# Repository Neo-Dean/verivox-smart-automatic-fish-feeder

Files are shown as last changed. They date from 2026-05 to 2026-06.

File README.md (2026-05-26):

# VERIVOX: Smart Aquarium Management System 🌊🤖

VERIVOX is an IoT-enabled smart fish feeder and water quality management system designed for residential aquariums. It ensures fish survival and optimal water chemistry through real-time monitoring, automated feeding schedules, and hierarchical safety lockouts.

## 🚀 Core Features
* **Priority Safety Lockouts:** Automatically halts feeding and triggers visual/mobile alarms if water pH crashes to toxic levels.
* **Smart Maintenance Alerts:** Continues offline feeding but alerts users when TDS or Turbidity thresholds indicate a dirty tank.
* **Dual-Redundancy Scheduling:** Syncs with the Arduino IoT Cloud via mobile UI sliders, backed by a local DS3231 RTC module to guarantee feeding even during total Wi-Fi blackouts.
* **Chemical Dosing Control:** Integrates an MD-102 driven peristaltic pump with 2FA mobile confirmation to safely correct pH imbalances.

## 💻 Tech Stack & Electronics
* **Microcontroller:** Arduino Nano 33 IoT
* **Cloud Infrastructure:** Arduino IoT Cloud (Dashboards & Webhooks)
* **Sensors:** pH, TDS, Turbidity, DS18B20 (Temperature for polynomial TDS compensation), HC-SR04 (Food level monitoring).
* **Actuators:** MG996R Servo (Feeder), Peristaltic Pump via MD-102 Driver.

## ⚙️ Open-Source Hardware & 3D Enclosure
The physical architecture of VERIVOX was custom-engineered using Fusion 360. All CAD files are provided in the `/3d model` directory to support the Open-Source Hardware (OSHW) community.

* **Interactive Assembly:** Click on the `VERIVOX_Full_Assembly.stl` file within GitHub to view and rotate the fully assembled hardware in 3D.
* **Manufacturing Ready:** Individual components (Main Body, Lid, Motor Mount, Worm-Screw, etc.) are provided in modern `.3mf` format, preserving crucial slicing data for 3D printing.

## 🧠 System Architecture Highlight
This repository contains the production firmware for the VERIVOX mainboard. The code is optimized to minimize server payload using delta thresholds (`thingProperties.h`) and features strict interrupt management (`IrReceiver.stop()`) to prevent timer conflicts between the IR hardware and PWM servo signals.

---
*Developed as a Final Year Software Engineering Project by Syajaratul Diana at Universiti Malaysia Sarawak (UNIMAS).*

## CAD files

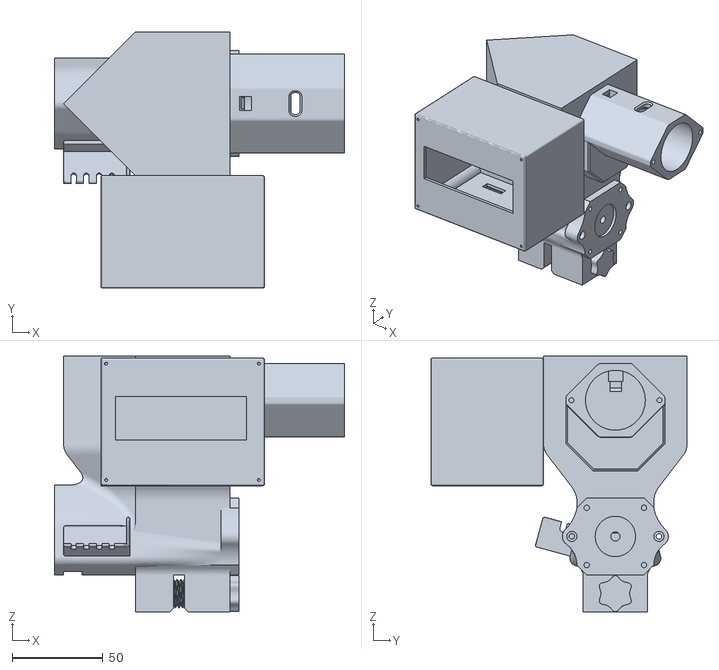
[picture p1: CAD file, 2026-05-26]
3d model/Assembled-automatic-fish-feeder.stl
159.5 x 141.0 x 140.6

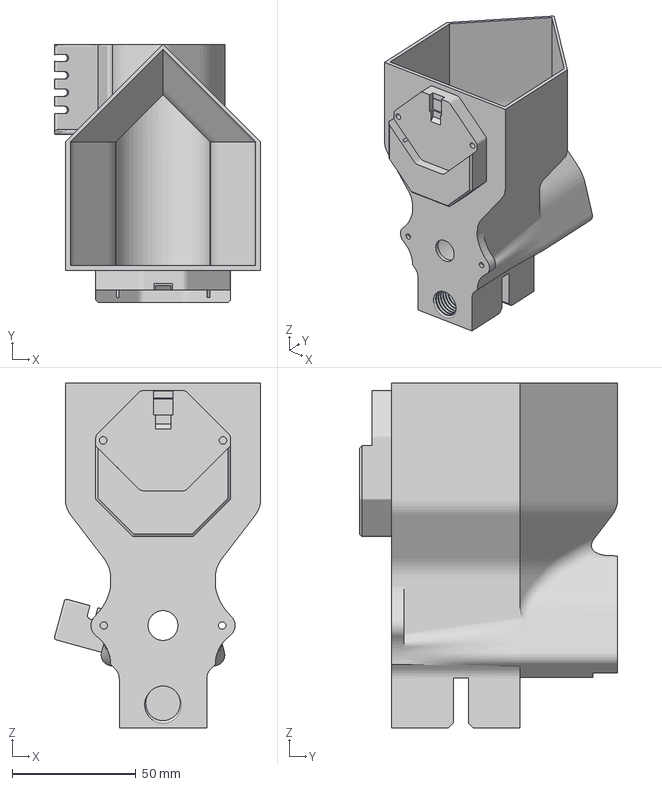
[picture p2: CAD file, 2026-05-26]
3d model/mainbody.3mf
83.5 x 104.5 x 139.6 mm

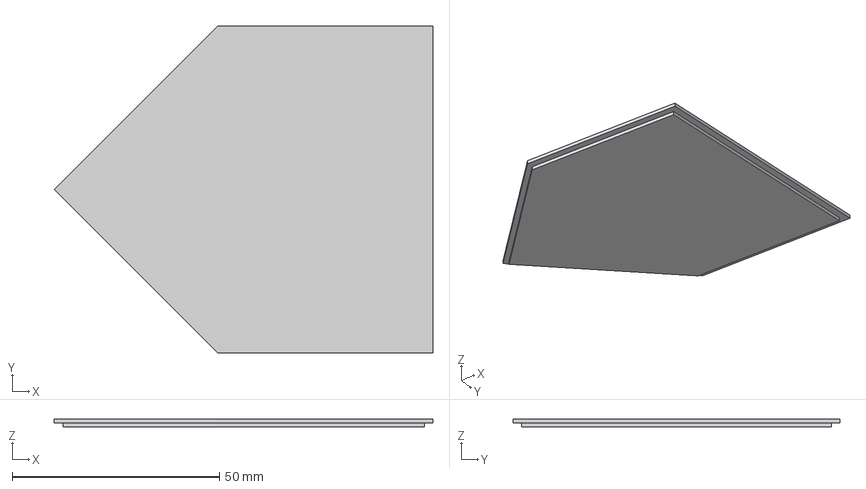
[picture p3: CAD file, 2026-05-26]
3d model/cover.3mf
91.5 x 79.0 x 2.00 mm

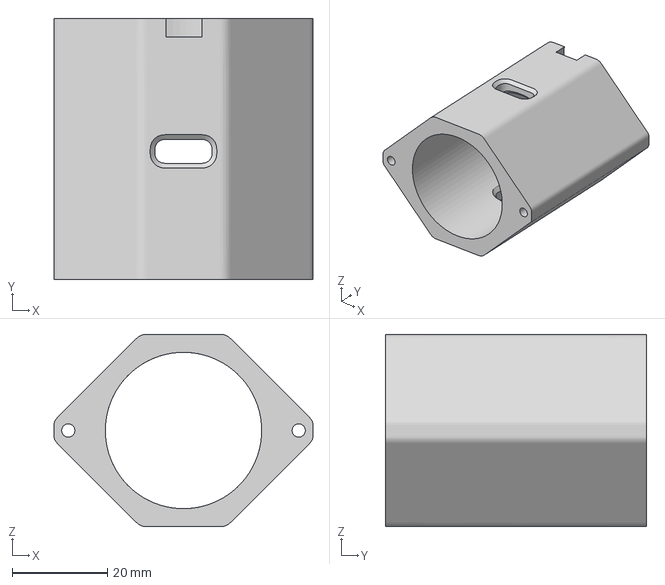
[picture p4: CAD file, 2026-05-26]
3d model/pump body.3mf
54.5 x 55.0 x 40.5 mm

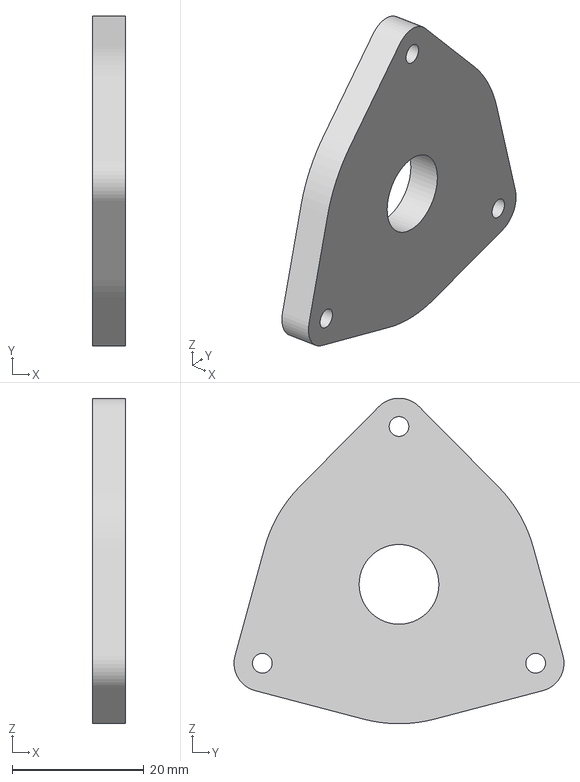
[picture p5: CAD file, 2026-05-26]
3d model/lock.3mf
5.00 x 50.1 x 49.4 mm

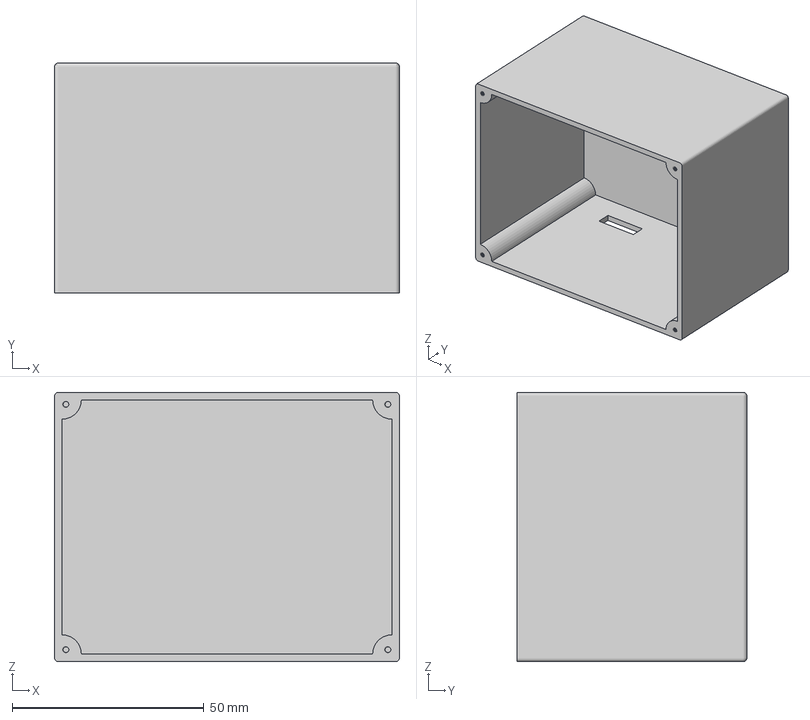
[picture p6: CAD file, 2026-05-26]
3d model/box.3mf
90.0 x 60.0 x 70.3 mm

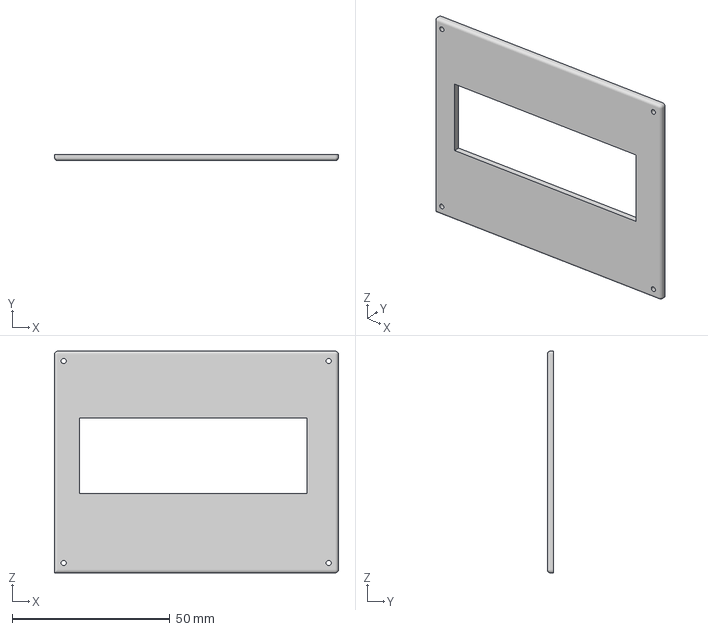
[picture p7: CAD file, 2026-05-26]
3d model/lid.3mf
90.0 x 2.00 x 70.3 mm

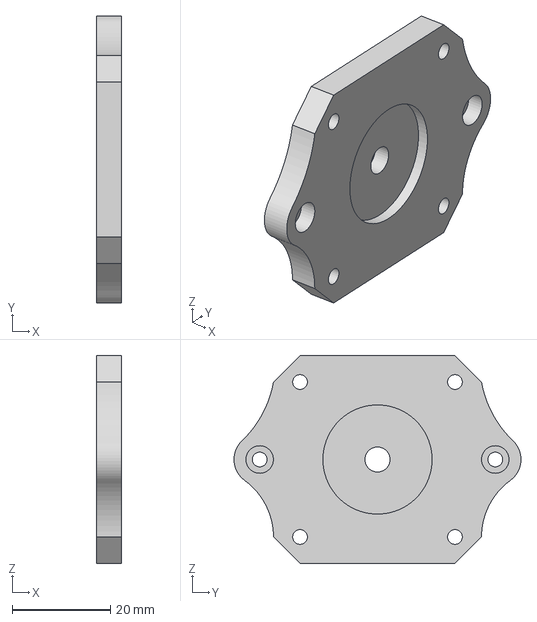
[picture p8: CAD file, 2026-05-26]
3d model/motor-mount.3mf
5.00 x 58.3 x 42.3 mm

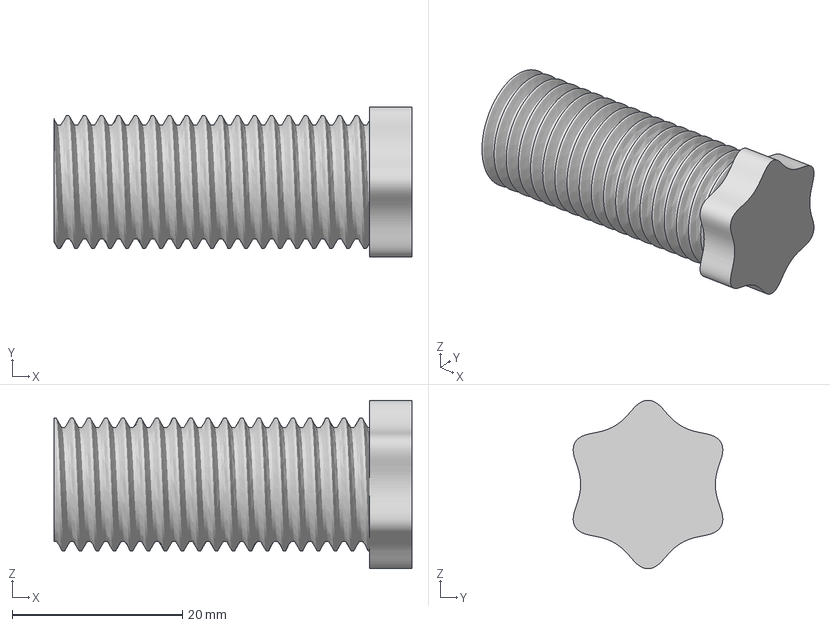
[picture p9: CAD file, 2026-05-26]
3d model/tightening-screw.3mf
42.1 x 17.6 x 19.8 mm

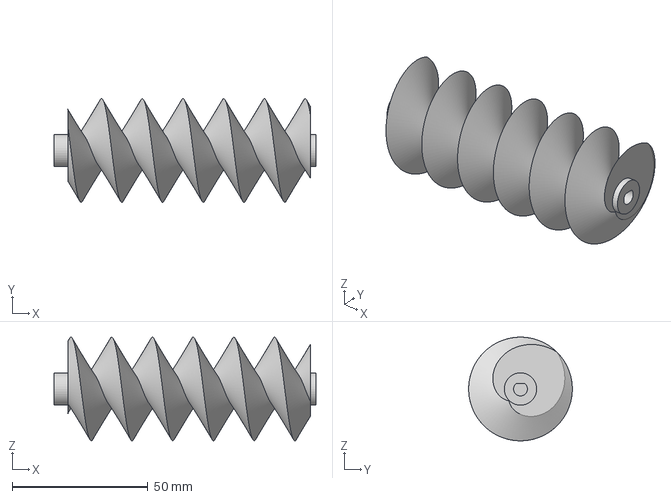
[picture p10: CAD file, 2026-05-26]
3d model/worm-screw.3mf
96.5 x 38.2 x 38.2 mm

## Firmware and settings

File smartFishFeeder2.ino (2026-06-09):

#include "thingProperties.h"
// 1. Core Communication (Must go first!)
#include <Wire.h>

// 2. LCD Screen Libraries
#include <hd44780.h>
#include <hd44780ioClass/hd44780_I2Cexp.h>

// 3. Sensors and Actuators
#include <OneWire.h>
#include <DallasTemperature.h>
#include <RTClib.h>
#include <IRremote.hpp>

// --- PIN DEFINITIONS ---
#define TDS_PIN       A0
#define PH_PIN        A1
#define TURBIDITY_PIN A2
#define TEMP_PIN      4
#define TRIG_PIN      2
#define ECHO_PIN      3
#define SERVO_PIN     9   // Sends HIGH trigger to Uno Pin 2
#define ONLINE_STATUS_PIN 7 // Sends Cloud status to Uno Pin 3
#define RELAY_PIN     6
#define IR_RECEIVE_PIN 8
#define BUZZER_PIN    10

// --- IR HEX CODES ---
const uint32_t IR_FEED_NOW    = 0xBA45FF00; // Button 1: Manual Feed
const uint32_t IR_CHECK_WATER = 0xB946FF00; // Button 2: Check Water
const uint32_t IR_DISPENSE_PH = 0xE31CFF00; // Button OK: Dispense pH
const uint32_t IR_UP_ARROW    = 0xE718FF00; // Arrow Up: Scroll Menu Back
const uint32_t IR_DOWN_ARROW  = 0xAD52FF00; // Arrow Down: Scroll Menu Forward

// --- MENU TRACKER ---
int currentMenuIndex = 0;
const int MAX_MENU_PAGES = 4; // 0=pH, 1=Temp, 2=TDS, 3=Turbidity, 4=Food

// --- OBJECTS ---
OneWire oneWire(TEMP_PIN);
DallasTemperature sensors(&oneWire);
hd44780_I2Cexp lcd; 
RTC_DS3231 myRTC;

// --- TIMERS & TRACKERS ---
unsigned long previousMillis = 0;
const long interval = 2000;
int lastFedHour = -1;

// --- CALIBRATION & THRESHOLDS ---
const int HOPPER_FULL_CM = 4;
const int HOPPER_EMPTY_CM = 15;
const float PH_OFFSET = 0.00;
const float TDS_WARNING_THRESHOLD = 400.0; // Maintenance alert threshold (ppm)
const int TURBIDITY_WARNING_THRESHOLD = 30; // Maintenance alert threshold (NTU)

void setup() {

  pinMode(LED_BUILTIN, OUTPUT);
  digitalWrite(LED_BUILTIN, HIGH);
  Serial.begin(9600);
  delay(1500);

  initProperties();
  ArduinoCloud.begin(ArduinoIoTPreferredConnection);
  setDebugMessageLevel(2);

  // --- DASHBOARD UI LABELS ---
  cloudHeaderMain = "VERIVOX";
  cloudLabelActions = "CONTROL CENTER";
  cloudLabelVitals = "REAL-TIME MONITORING";
  cloudLabelAnalytics = "SYSTEM LOGS & HISTORY";
  cloudSystemOnline = true; // Turns on the dashboard LED widget

  // Initialize Defaults for Sliders in case of offline boot
  if (userMorningHour == 0) userMorningHour = 7;
  if (userEveningHour == 0) userEveningHour = 19;
  
  // Force the slider to 400ms if it gets wiped
  if (userFeedDuration == 0) userFeedDuration = 400; 

  sensors.begin();

  lcd.begin(16, 2);
  lcd.backlight();
  lcd.setCursor(0, 0);
  lcd.print("VeriVox Booting.");

  if (!myRTC.begin()) {
    Serial.println("Couldn't find RTC module!");
  }

  // Initialize Communication Pins to Uno
  pinMode(SERVO_PIN, OUTPUT);
  digitalWrite(SERVO_PIN, LOW); 
  
  pinMode(ONLINE_STATUS_PIN, OUTPUT);
  digitalWrite(ONLINE_STATUS_PIN, LOW); 

  // Initialize Sensors
  pinMode(TRIG_PIN, OUTPUT);
  pinMode(ECHO_PIN, INPUT);
  
  // Initialize Buzzer
  pinMode(BUZZER_PIN, OUTPUT);
  digitalWrite(BUZZER_PIN, LOW); // Start off

  // ACTIVE-HIGH RELAY 
  pinMode(RELAY_PIN, OUTPUT);
  digitalWrite(RELAY_PIN, LOW); // Force the Nano to stay quiet (0V) at boot

  // Initialize IR Receiver
  IrReceiver.begin(IR_RECEIVE_PIN, DISABLE_LED_FEEDBACK);

  setRGB(0, 0, 255); // Triggers dummy function

  // Startup dual-beep
  beepBuzzer(150);
  delay(100);
  beepBuzzer(150);
}

void loop() {
  ArduinoCloud.update();

  // Tell Uno our cloud status
  if (ArduinoCloud.connected()) {
    digitalWrite(ONLINE_STATUS_PIN, HIGH);
  } else {
    digitalWrite(ONLINE_STATUS_PIN, LOW);
  }

  checkIRRemote();

  unsigned long currentMillis = millis();
  if (currentMillis - previousMillis >= interval) {
    previousMillis = currentMillis;
    readAndSyncSensors();
    checkFoodLevel();
    updateLCD();
    checkOfflineSchedule();
  }
}

// --- CORE SENSOR FUNCTIONS ---

void readAndSyncSensors() {
  sensors.requestTemperatures();
  float tempC = sensors.getTempCByIndex(0);
  if (tempC != -127.00) cloudTemperature = tempC;

  long phTotal = 0;
  for (int i = 0; i < 10; i++) {
    phTotal += analogRead(PH_PIN);
    delay(10);
  }
  float phAverage = phTotal / 10.0;
  float phVoltage = (phAverage / 1024.0) * 3.3;
  cloudPH = (3.5 * phVoltage) + PH_OFFSET;
  cloudPH = constrain(cloudPH, 0.0, 14.0);

  float tdsVoltage = (analogRead(TDS_PIN) / 1024.0) * 3.3;
  float compCoeff = 1.0 + 0.02 * (cloudTemperature - 25.0);
  float compVolt = tdsVoltage / compCoeff;
  cloudTDS = (133.42 * pow(compVolt, 3) - 255.86 * pow(compVolt, 2) + 857.39 * compVolt) * 0.5;

  int rawTurbidity = analogRead(TURBIDITY_PIN);
  cloudTurbidity = map(rawTurbidity, 0, 1023, 0, 100);

  checkWaterQuality();
}

void checkFoodLevel() {
  digitalWrite(TRIG_PIN, LOW);
  delayMicroseconds(2);
  digitalWrite(TRIG_PIN, HIGH);
  delayMicroseconds(10);
  digitalWrite(TRIG_PIN, LOW);

  long duration = pulseIn(ECHO_PIN, HIGH, 30000);
  if (duration == 0) duration = (HOPPER_EMPTY_CM * 2) / 0.034;

  long distance = duration * 0.034 / 2;
  int percentage = map(distance, HOPPER_FULL_CM, HOPPER_EMPTY_CM, 100, 0);
  cloudFoodLevel = constrain(percentage, 0, 100);

  cloudFoodLowAlert = (cloudFoodLevel <= 20);
}

void checkWaterQuality() {
  if (cloudPH < 6.5 || cloudPH > 8.5) {
    cloudPHAlert = true;
    cloudWaterWarning = true;
    cloudIsWaterSafe = false; 
    setRGB(255, 0, 0);        
  }
  else if (cloudTDS > TDS_WARNING_THRESHOLD || cloudTurbidity > TURBIDITY_WARNING_THRESHOLD) {
    cloudPHAlert = false;
    cloudWaterWarning = true;
    cloudIsWaterSafe = true;  
    setRGB(255, 128, 0);      
  }
  else {
    cloudPHAlert = false;
    cloudWaterWarning = false;
    cloudIsWaterSafe = true;  

    if (cloudFoodLevel <= 10) {
      setRGB(255, 0, 0);      
    } else if (cloudFoodLowAlert) {
      setRGB(255, 255, 0);    
    } else {
      setRGB(0, 255, 0);      
    }
  }
}

void updateLCD() {
  lcd.clear();
  
  // Always print the system name centered on the top row
  lcd.setCursor(4, 0);
  lcd.print("VERIVOX");
  
  // Switch the bottom row based on the current remote selection
  lcd.setCursor(0, 1);
  switch(currentMenuIndex) {
    case 0:
      lcd.print("pH Level: "); 
      lcd.print(cloudPH, 1);
      break;
    case 1:
      lcd.print("Temp: "); 
      lcd.print(cloudTemperature, 1); 
      lcd.print(" C");
      break;
    case 2:
      lcd.print("TDS: "); 
      lcd.print(cloudTDS, 0); 
      lcd.print(" ppm");
      break;
    case 3:
      lcd.print("Turbidity: "); 
      lcd.print(cloudTurbidity); 
      lcd.print("%");
      break;
    case 4:
      lcd.print("Food Lvl: "); 
      lcd.print(cloudFoodLevel); 
      lcd.print("%");
      break;
  }
}

void beepBuzzer(int duration) {
  digitalWrite(BUZZER_PIN, HIGH);
  delay(duration);
  digitalWrite(BUZZER_PIN, LOW);
}

// --- SCHEDULING & ACTUATOR FUNCTIONS ---

void checkOfflineSchedule() {
  DateTime now = myRTC.now();

  int morningFeed = (userMorningHour != 0) ? userMorningHour : 7;
  int eveningFeed = (userEveningHour != 0) ? userEveningHour : 19;

  if (now.hour() == morningFeed && now.minute() == 0 && lastFedHour != morningFeed) {
    if (!cloudIsWaterSafe) {
      cloudLastFeedingStatus = "SKIPPED (pH Unsafe)";
      beepBuzzer(500); delay(100); beepBuzzer(500);
    } else if (cloudFoodLevel <= 10) {
      cloudLastFeedingStatus = "SKIPPED (Hopper Empty!)";
      beepBuzzer(500); delay(100); beepBuzzer(500);
    } else {
      executeMotorSequence();
      cloudFeedingCount++;
      cloudLastFeedingStatus = cloudWaterWarning ? "Fed Morning (CLEAN TANK!)" : (cloudFoodLowAlert ? "Fed Morning (REFILL FOOD!)" : "Success (Morning)");
    }
    lastFedHour = morningFeed;
  }

  if (now.hour() == eveningFeed && now.minute() == 0 && lastFedHour != eveningFeed) {
    if (!cloudIsWaterSafe) {
      cloudLastFeedingStatus = "SKIPPED (pH Unsafe)";
      beepBuzzer(500); delay(100); beepBuzzer(500);
    } else if (cloudFoodLevel <= 10) {
      cloudLastFeedingStatus = "SKIPPED (Hopper Empty!)";
      beepBuzzer(500); delay(100); beepBuzzer(500);
    } else {
      executeMotorSequence();
      cloudFeedingCount++;
      cloudLastFeedingStatus = cloudWaterWarning ? "Fed Evening (CLEAN TANK!)" : (cloudFoodLowAlert ? "Fed Evening (REFILL FOOD!)" : "Success (Evening)");
    }
    lastFedHour = eveningFeed;
  }

  if (now.hour() != morningFeed && now.hour() != eveningFeed) {
    lastFedHour = -1;
  }
}

void executeMotorSequence() {
  setRGB(0, 0, 255); 
  beepBuzzer(200); 
  
  // If the slider is set to 0, default to a quick 400ms flick
  int spinTime = (userFeedDuration > 0) ? userFeedDuration : 400; 
  
  // 1. Send the HIGH trigger to the Uno to start spinning the auger
  digitalWrite(SERVO_PIN, HIGH); 
  
  // 2. Wait for the designated duration
  delay(spinTime); 
  
  // 3. Send the LOW trigger to the Uno to stop the motor
  digitalWrite(SERVO_PIN, LOW);  
  
  checkWaterQuality(); 
}

void dispensePHTreatment() {
  Serial.println("Activating pH Pump...");
  lcd.clear();
  lcd.print("Pumping pH Fix..");

  setRGB(255, 0, 255);

  // --- TRIGGER THE UNO BRIDGE ---
  digitalWrite(RELAY_PIN, HIGH); // Send 3.3V to Uno Pin 4 to turn pump ON
  delay(2000);
  digitalWrite(RELAY_PIN, LOW);  // Drop to 0V so Uno turns pump OFF

  cloudPHTreatmentCount++;
  cloudLastPHTreatment = "Today";
  updateLCD();

  checkWaterQuality();
}

// --- IR REMOTE FUNCTIONS ---

void checkIRRemote() {
  if (IrReceiver.decode()) {
    uint32_t receivedCode = IrReceiver.decodedIRData.decodedRawData;

    if (receivedCode == IR_FEED_NOW) {
      performManualFeedingWithIR();
    }
    else if (receivedCode == IR_CHECK_WATER) {
      lcd.clear();
      lcd.setCursor(2, 0);
      lcd.print("Scanning");
      lcd.setCursor(2, 1);
      lcd.print("Sensors...");
      delay(500);
      readAndSyncSensors();
      updateLCD();
    }
    else if (receivedCode == IR_DISPENSE_PH) {
      if (cloudPHAlert) {
        dispensePHTreatment();
      } else {
        lcd.clear();
        lcd.print("pH is Normal!");
        delay(1500);
        updateLCD();
      }
    }
    // --- SCROLLING LOGIC ---
    else if (receivedCode == IR_UP_ARROW) {
      currentMenuIndex--; // Go to previous sensor
      if (currentMenuIndex < 0) currentMenuIndex = MAX_MENU_PAGES; // Wrap around to end
      updateLCD();
      beepBuzzer(50); // Tiny click sound when scrolling
    }
    else if (receivedCode == IR_DOWN_ARROW) {
      currentMenuIndex++; // Go to next sensor
      if (currentMenuIndex > MAX_MENU_PAGES) currentMenuIndex = 0; // Wrap around to start
      updateLCD();
      beepBuzzer(50); 
    }

    IrReceiver.resume();
  }
}

void performManualFeedingWithIR() {
  if (!cloudIsWaterSafe) {
    beepBuzzer(500); delay(100); beepBuzzer(500);
    lcd.clear();
    lcd.print("Feed Blocked!");
    lcd.setCursor(0, 1);
    lcd.print("pH Unsafe!");
    delay(2000);
    updateLCD();

  } else if (cloudFoodLevel <= 10) {
    beepBuzzer(500); delay(100); beepBuzzer(500);
    lcd.clear();
    lcd.print("Feed Blocked!");
    lcd.setCursor(0, 1);
    lcd.print("Hopper Empty!");
    delay(2000);
    updateLCD();

  } else {
    executeMotorSequence();
    cloudFeedingCount++;

    if (cloudWaterWarning) {
      cloudLastFeedingStatus = "IR Fed (CLEAN TANK!)";
    } else if (cloudFoodLowAlert) {
      cloudLastFeedingStatus = "IR Fed (REFILL FOOD!)";
    } else {
      cloudLastFeedingStatus = "Success (IR Remote)";
    }
  }
}

// --- CLOUD CALLBACK FUNCTIONS ---

void onCloudManualFeedChange() {
  if (cloudManualFeed) {

    if (!cloudIsWaterSafe) {
      cloudLastFeedingStatus = "SKIPPED (pH Unsafe)";
      beepBuzzer(500); delay(100); beepBuzzer(500);

    } else if (cloudFoodLevel <= 10) {
      cloudLastFeedingStatus = "SKIPPED (Hopper Empty!)";
      beepBuzzer(500); delay(100); beepBuzzer(500);

    } else {
      executeMotorSequence();
      cloudFeedingCount++;

      if (cloudWaterWarning) {
        cloudLastFeedingStatus = "Fed (CLEAN TANK!)";
      } else if (cloudFoodLowAlert) {
        cloudLastFeedingStatus = "Fed (REFILL FOOD!)";
      } else {
        cloudLastFeedingStatus = "Success (Manual)";
      }
    }

    cloudManualFeed = false;
  }
}

// MATCHED EXACTLY TO THINGPROPERTIES.H EXPECTATIONS
void onCloudPhtreatmentConfirmedChange() {
  if (cloudPHTreatmentConfirmed) {
    dispensePHTreatment();
    cloudPHTreatmentConfirmed = false;
  }
}

void onCloudRefillHopperChange() {
  if (cloudRefillHopper) {
    cloudFoodLowAlert = false;
    cloudRefillHopper = false;
  }
}

void onUserMorningHourChange() { }
void onUserEveningHourChange() { }  

void onUserFeedDurationChange() { }

// --- THE DUMMY RGB FUNCTION ---
// Keeps old sensor code from crashing!
void setRGB(int r, int g, int b) {
  // Intentionally left blank. The Uno handles the lights now!
}
